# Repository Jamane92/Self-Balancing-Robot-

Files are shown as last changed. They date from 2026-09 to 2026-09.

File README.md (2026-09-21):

# Self-Balancing-Robot-

--FRANCAIS--

Ce projet à été réalisé individuellement en parallèle de mes études, reprend un projet que nous avions réalisé en ING1 à l'ECE Paris. Mais cette fois, au lieu de tout avoir déjà donné et pensé dans un kit, je me suis lancé le défi de tout faire moi même, de A à Z, de la 3D à la création du PCB, au codage du PID. Voici le résultat final : 

--ENGLISH

I carried out this project independently alongside my studies, revisiting a project we had originally completed during our first year of engineering school (ING1) at ECE Paris. This time, however, instead of using a kit where everything was pre-designed and provided, I challenged myself to build the entire thing from scratch—from 3D modeling and PCB design to programming the PID controller. Here is the final result : 

<p align="center">
  Self_Balancing
</p>

<p align="center">
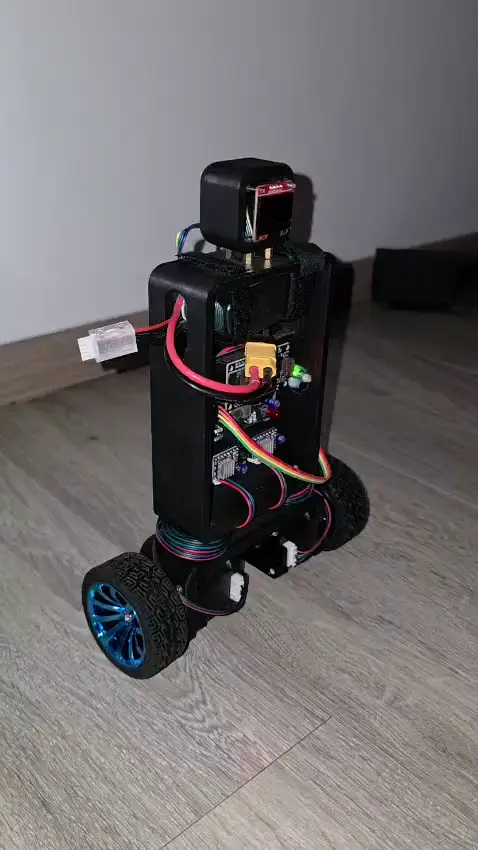
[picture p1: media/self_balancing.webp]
Démonstration du robot
  
</p>

--FRANCAIS--
Si souhaité, ce robort peut-être transformé en robot télécommandé, il suffit simplement de créer un serveur web sur l'EPS32 et d'y ajouter une modification de la consigne d'angle, ou de set un pitch/roll cible. 

Les difficultés rencontrés ont été sur le codage du PID, le fait que le buck-down choisi, le Mini360, ne donnait probablement pas suffisament de courant, bridant le couple et compliquant ainsi le codage du PID, j'ai également eu quelque problèmes avec le placement de mon MPU-6050, qui est un module bassse qualité, qui m'a beaucoup ralenti, en effet, pas malin d'acheter le coeur du projet à 3e sur Aliexpress au lieu de 15e chez le constructeur. Egalement celui-ci à été mal placé, ce que j'ai corrigé avec le point de col sur le coté pour le mettre à l'horizontal et non à la verticale ccomme il l'était. Aussi, j'ai "verser du cuivre" en GND sous l'antenne, ce qui n'est pas bon pour l'intégrité du signal radio et réduisait ainsi mes performances WIFI. C'est néanmoins un premier projet validé, qui me donne confiance pour plonger plus en détail dans le monde des PCB et de la conception hardware. 

--ENGLISH--
If desired, this robot can be converted into a remote-controlled unit; this simply requires setting up a web server on the ESP32 and adding a way to modify the angle setpoint or define a target pitch/roll.

I encountered difficulties with the PID coding, partly because the chosen step-down converter (the Mini360) likely didn't supply enough current—limiting torque and complicating PID tuning. I also faced issues with the placement of the MPU-6050; it was a low-quality module that really slowed me down—in hindsight, buying the project's core component for €3 on AliExpress instead of €15 from the manufacturer wasn't the smartest move. Furthermore, its initial positioning was incorrect; I fixed this by mounting it horizontally (using a side-mounted glue point) rather than vertically as it had been before. Finally, I had "poured copper" (a ground plane) beneath the antenna, which compromised radio signal integrity and reduced Wi-Fi performance. It is, however, a first project successfully completed, giving me the confidence to delve deeper into the world of PCBs and hardware design.

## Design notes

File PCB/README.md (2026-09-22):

--FRANCAIS-- 

Voici la section PCB du projet, j'y expose l'intégralité des documents nécessaires pour récupéerer le projet. Ce projet avait avant tout pour but de m'initier à la création de mon tout premier PCB, il n'utilise que des composants THT ou module complet que j'ai implémenté sur le PCB. Voici à quoi ressemble la 3D de mon PCB : 

--ENGLISH--

Here is the PCB section of the project; I have provided all the necessary documents to replicate it. The primary goal of this project was to learn how to design my very first PCB; it uses only through-hole (THT) components or complete modules that I mounted onto the board. Here is what the 3D view of my PCB looks like:

<p align="center">
  3D2
</p>

<p align="center">
  3D3
</p>

--FRANCAIS--

Et voici le routage, gardez à l'esprit que c'est mon tout premier PCB, avec que des composants THT, sans copper zone pour la puissance par exemple, sans plan de masse correct garantissant des EMI basses et une intégrité du signal, même si sur ce genre d'application, on est loin d'avoir ce genre de problème. L'important pour moi à ce moment là, c'était que ca marche, pour me donner la confiance d'aller sur des projets plus poussés.

--ENGLISH--

And here is the routing; keep in mind that this is my very first PCB, using only through-hole components, with no copper pour and no proper ground plane to ensure low EMI and signal integrity—though for this type of application, such issues are far from being a concern. The important thing for me at that point was for it to work, to give me the confidence to take on more advanced projects.

<p align="center">
robot
</p>

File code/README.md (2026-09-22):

--FRANCAIS-- 

Le code repose sur un concept d'automatisation utilisé partout dans le monde : le PID. Voici à quoi cela ressemble en théorie : 

<p align="center">
pid
</p>

Voici un site qui expliquera mieux que moi le concept de cet algorithme de contrôle : https://www.wattco.com/fr/2024/07/controleur-pid-explique/

--ENGLISH--

The code is based on an automation concept used worldwide: PID. Here up there is what it looks like in theory.
Here is a site that explains the concept of this control algorithm better than I can: https://www.wattco.com/fr/2024/07/controleur-pid-explique/

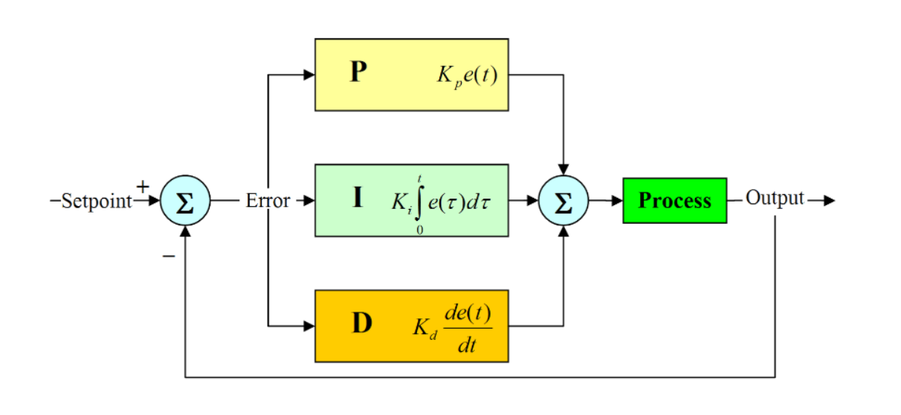
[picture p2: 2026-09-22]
media/pid.png

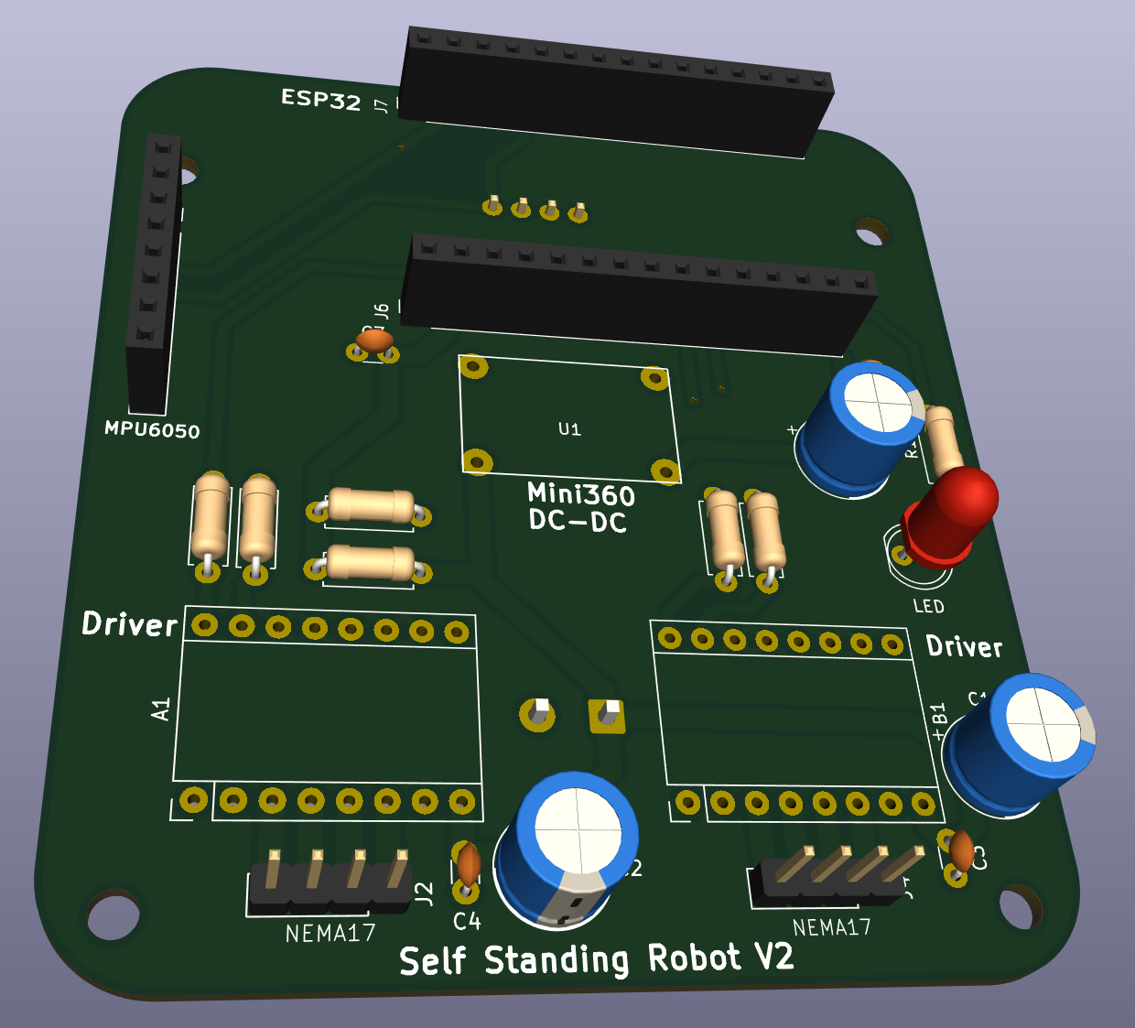
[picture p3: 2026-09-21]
media/3D2.png

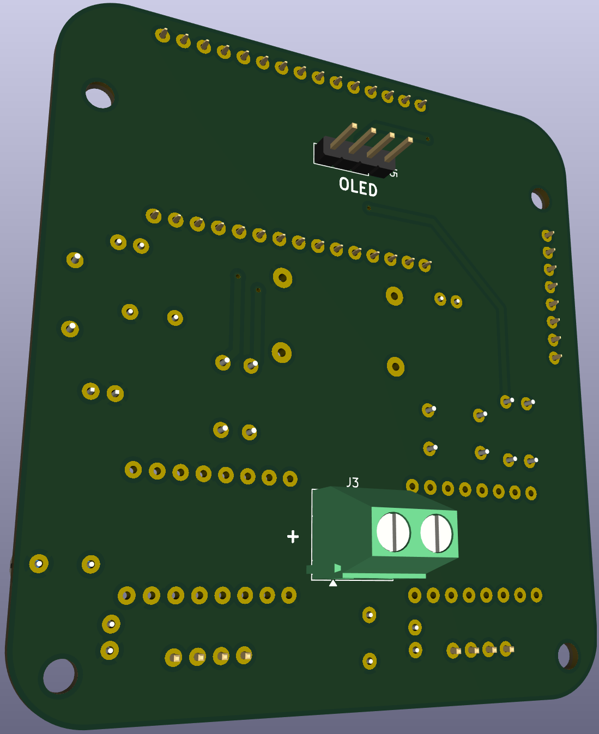
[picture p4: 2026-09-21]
media/3D3.png

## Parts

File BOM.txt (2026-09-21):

2x NEMA 17 DC motor 
2x DRV8825 motor driver
1x 3S1P Lipo battery 
1x ESP32 generic module 
1x Mini360 buck-down 
1x MPU-6050
1x SSD1306 OLED

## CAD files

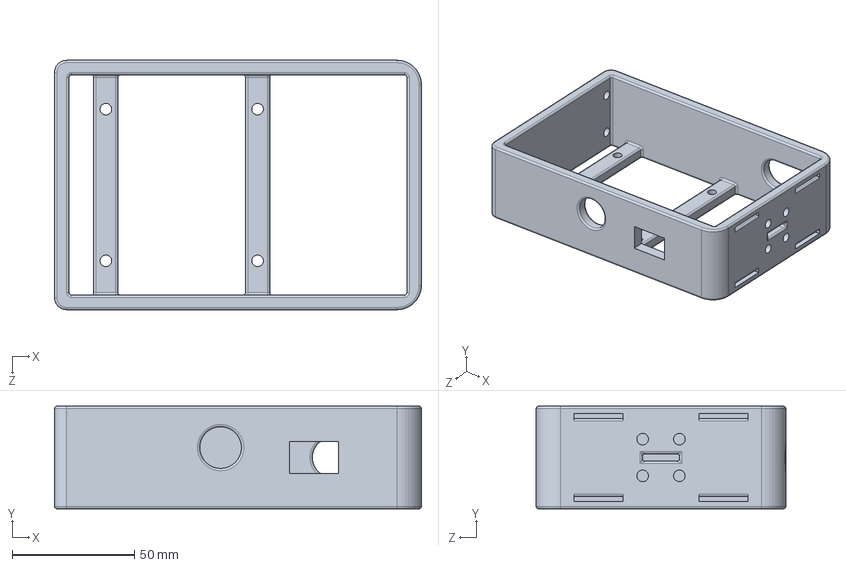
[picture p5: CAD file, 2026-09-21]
3D/body.SLDPRT
150.0 x 42.0 x 102.0 mm

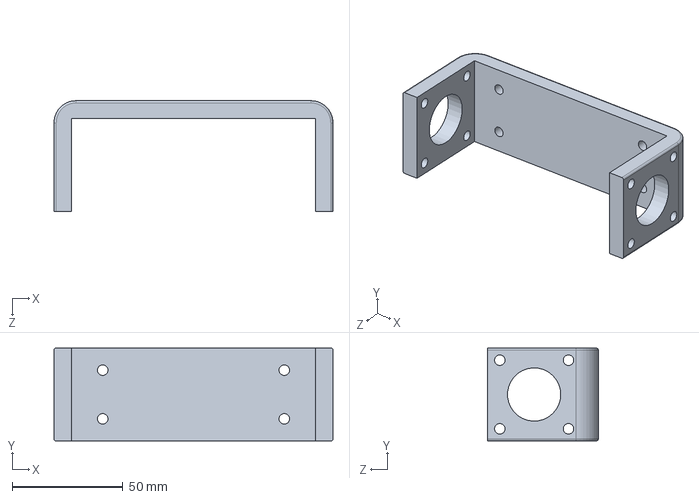
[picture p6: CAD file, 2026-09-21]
3D/legs.SLDPRT
126.0 x 42.0 x 50.0 mm

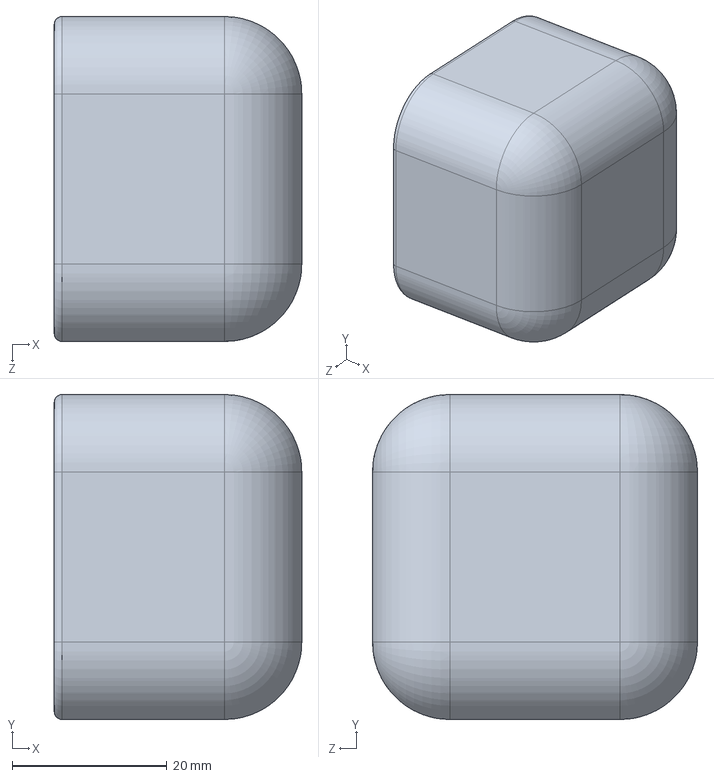
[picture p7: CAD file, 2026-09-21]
3D/head.SLDPRT
32.0 x 42.0 x 42.0 mm

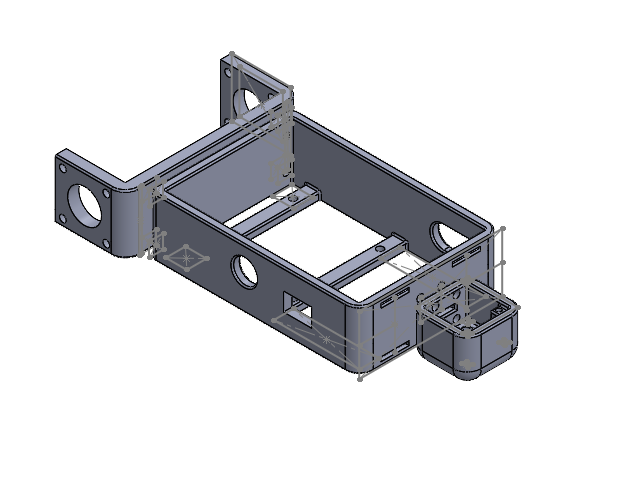
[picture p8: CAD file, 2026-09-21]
3D/assembly.SLDASM
Pièce1
Pièce2_V2
Pièce3_V2

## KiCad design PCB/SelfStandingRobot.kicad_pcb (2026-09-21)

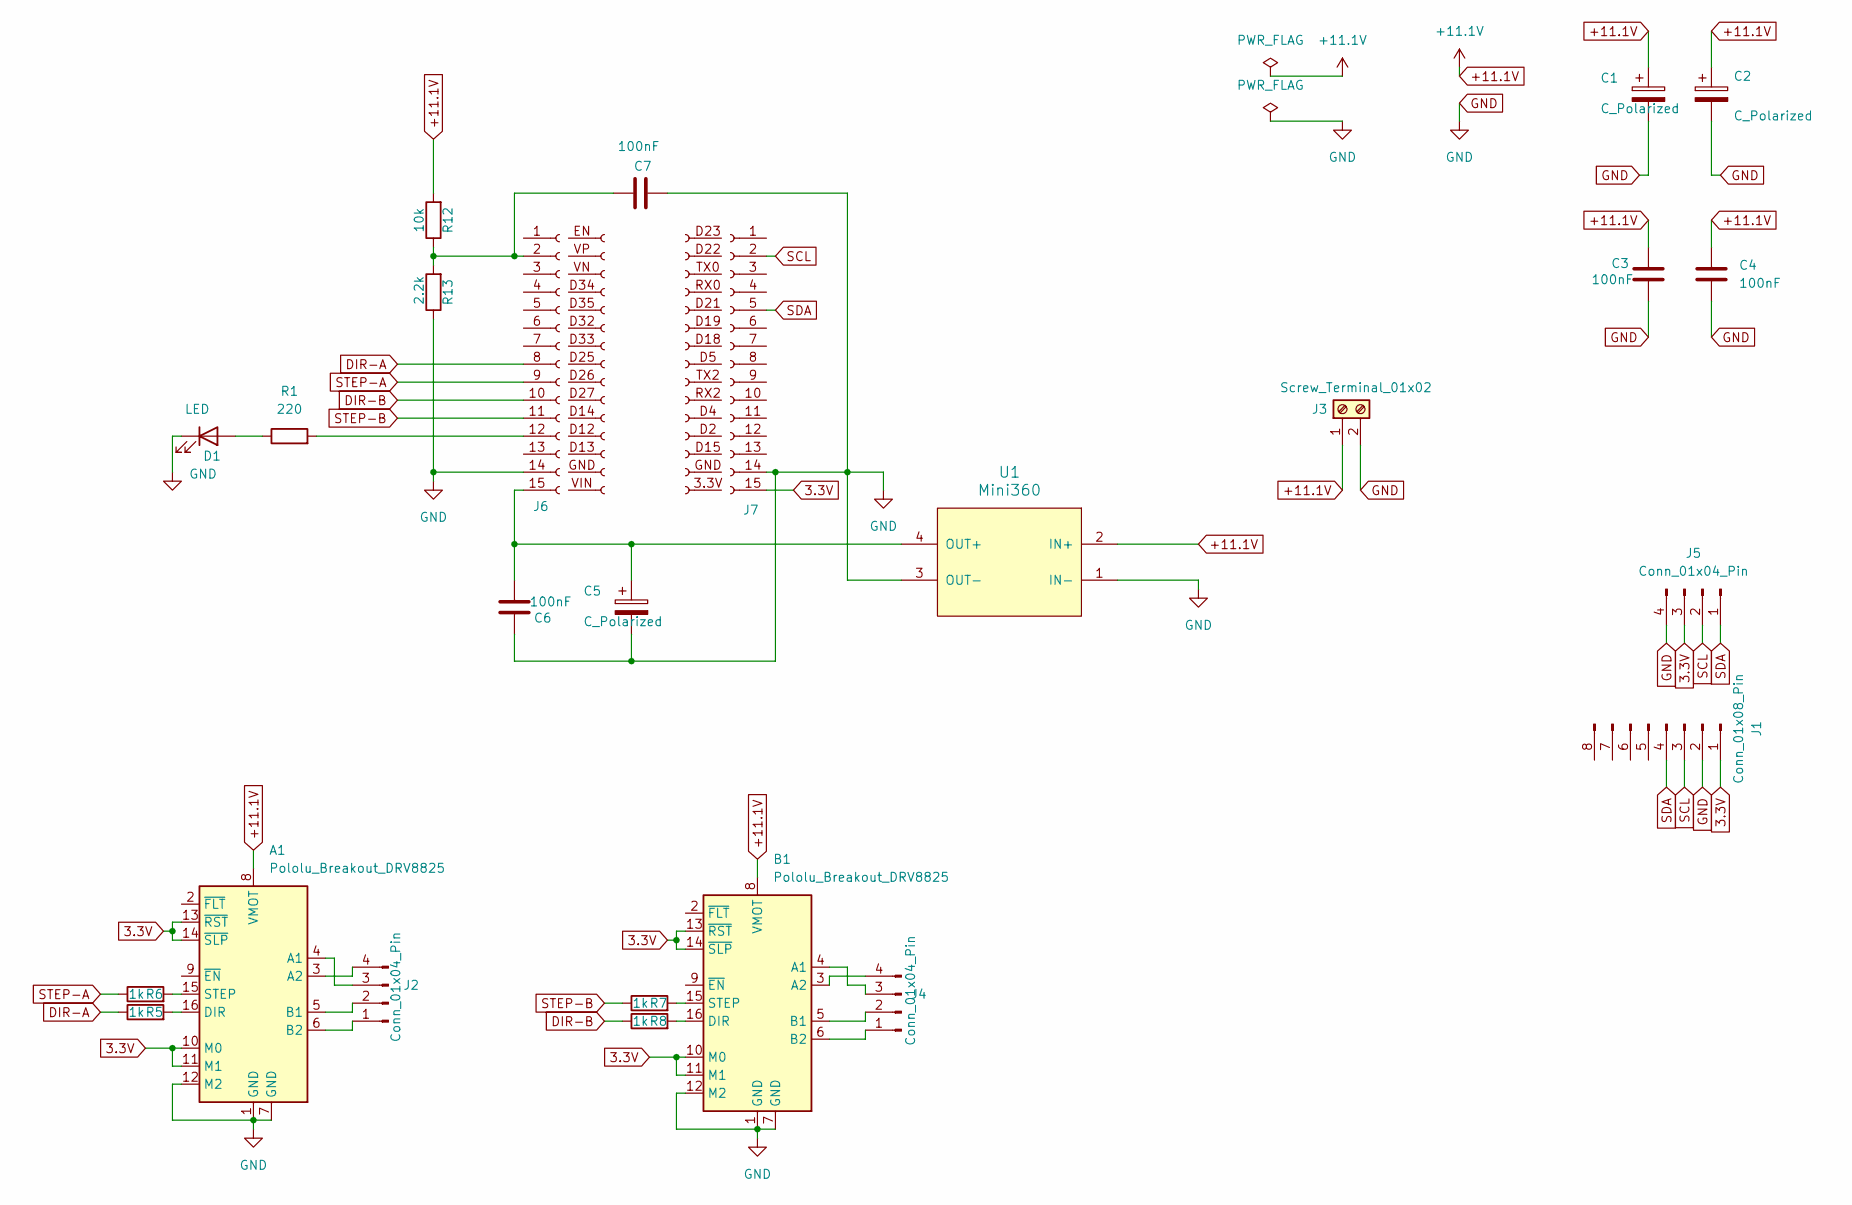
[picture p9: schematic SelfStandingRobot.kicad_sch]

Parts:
A1: Pololu_Breakout_DRV8825; Pololu_Breakout-16_15.2x20.3mm
B1: Pololu_Breakout_DRV8825; Pololu_Breakout-16_15.2x20.3mm
C1, C2, C5: C_Polarized; CP_Radial_D8.0mm_P5.00mm
C3, C4, C6, C7: 100nF; C_Disc_D3.0mm_W1.6mm_P2.50mm
D1: LED; LED_D5.0mm
J1: Conn_01x08_Pin; PinSocket_1x08_P2.54mm_Vertical
J2, J4, J5: Conn_01x04_Pin; PinHeader_1x04_P2.54mm_Vertical
J3: Screw_Terminal_01x02; TerminalBlock_Phoenix_MKDS-1,5-2-5.08_1x02_P5.08mm_Horizont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
J6, J7: Conn_01x15_Socket; PinSocket_1x15_P2.54mm_Vertical
J9, J10: Conn_01x15_Socket
R1: 220; R_Axial_DIN0207_L6.3mm_D2.5mm_P7.62mm_Horizontal
R5, R6, R7, R8: 1k; R_Axial_DIN0207_L6.3mm_D2.5mm_P7.62mm_Horizontal
R12: 10k; R_Axial_DIN0207_L6.3mm_D2.5mm_P7.62mm_Horizontal
R13: 2.2k; R_Axial_DIN0207_L6.3mm_D2.5mm_P7.62mm_Horizontal
U1: Mini360; Mini360_Step-Down

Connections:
3.3V: A1.10 (M0), A1.11 (M1), A1.13 (~RST), A1.14 (~SLP), B1.10 (M0), B1.11 (M1), B1.13 (~RST), B1.14 (~SLP), J1.1, J5.3, J7.15 (3.3V)
+11.1V: A1.8 (VMOT), B1.8 (VMOT), C1.1, C2.1, C3.1, C4.1, J3.1, R12.2, U1.2 (IN+)
DIR-A: J6.8 (D25), R5.1
DIR-B: J6.10 (D27), R8.1
GND: A1.1 (GND), A1.7 (GND), A1.12 (M2), B1.1 (GND), B1.7 (GND), B1.12 (M2), C1.2, C2.2, C3.2, C4.2, C5.2, C6.1, C7.1, D1.1 (K), J1.2, J3.2, J5.4, J6.14 (GND), J7.14 (GND), R13.1, U1.1 (IN-), U1.3 (OUT-)
unnamed: A1.4 (A1), J2.3
unnamed: A1.3 (A2), J2.4
unnamed: A1.5 (B1), J2.2
unnamed: A1.6 (B2), J2.1
unnamed: A1.16 (DIR), R5.2
unnamed: A1.15 (STEP), R6.2
unnamed: B1.4 (A1), J4.3
unnamed: B1.3 (A2), J4.4
unnamed: B1.5 (B1), J4.2
unnamed: B1.6 (B2), J4.1
unnamed: B1.16 (DIR), R8.2
unnamed: B1.15 (STEP), R7.2
unnamed: D1.2 (A), R1.1
unnamed: J6.12 (D12), R1.2
unnamed: C5.1, C6.2, J6.15 (VIN), U1.4 (OUT+)
unnamed: C7.2, J6.2 (VP), R12.1, R13.2
SCL: J1.3, J5.2, J7.2 (D22)
SDA: J1.4, J5.1, J7.5 (D21)
STEP-A: J6.9 (D26), R6.1
STEP-B: J6.11 (D14), R7.1

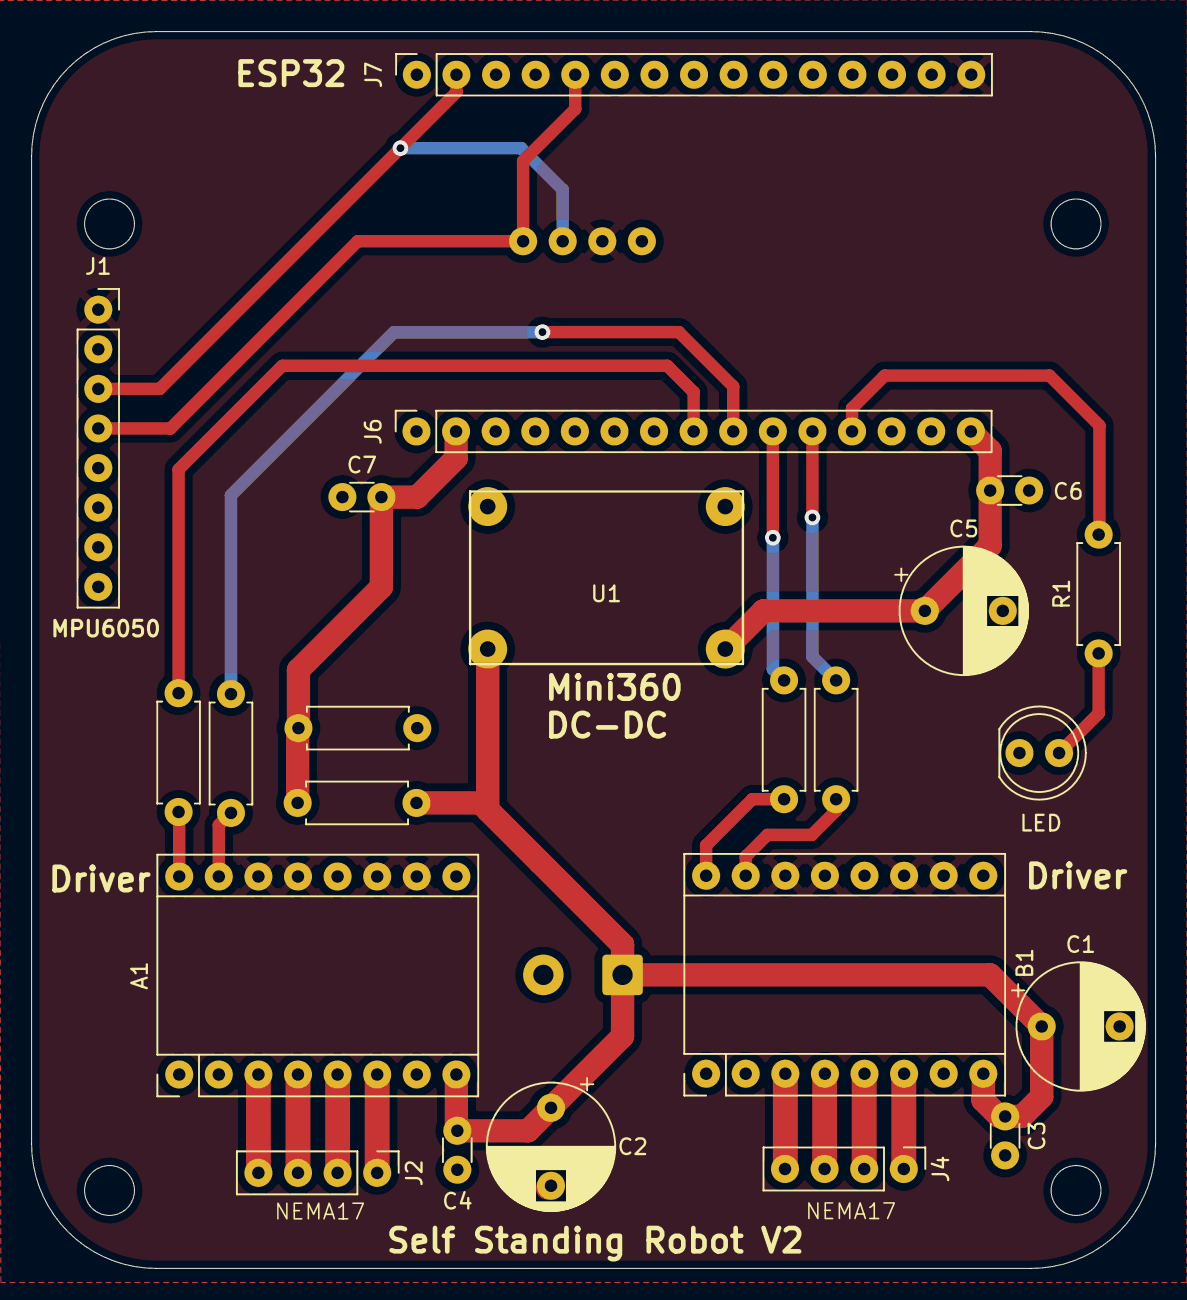
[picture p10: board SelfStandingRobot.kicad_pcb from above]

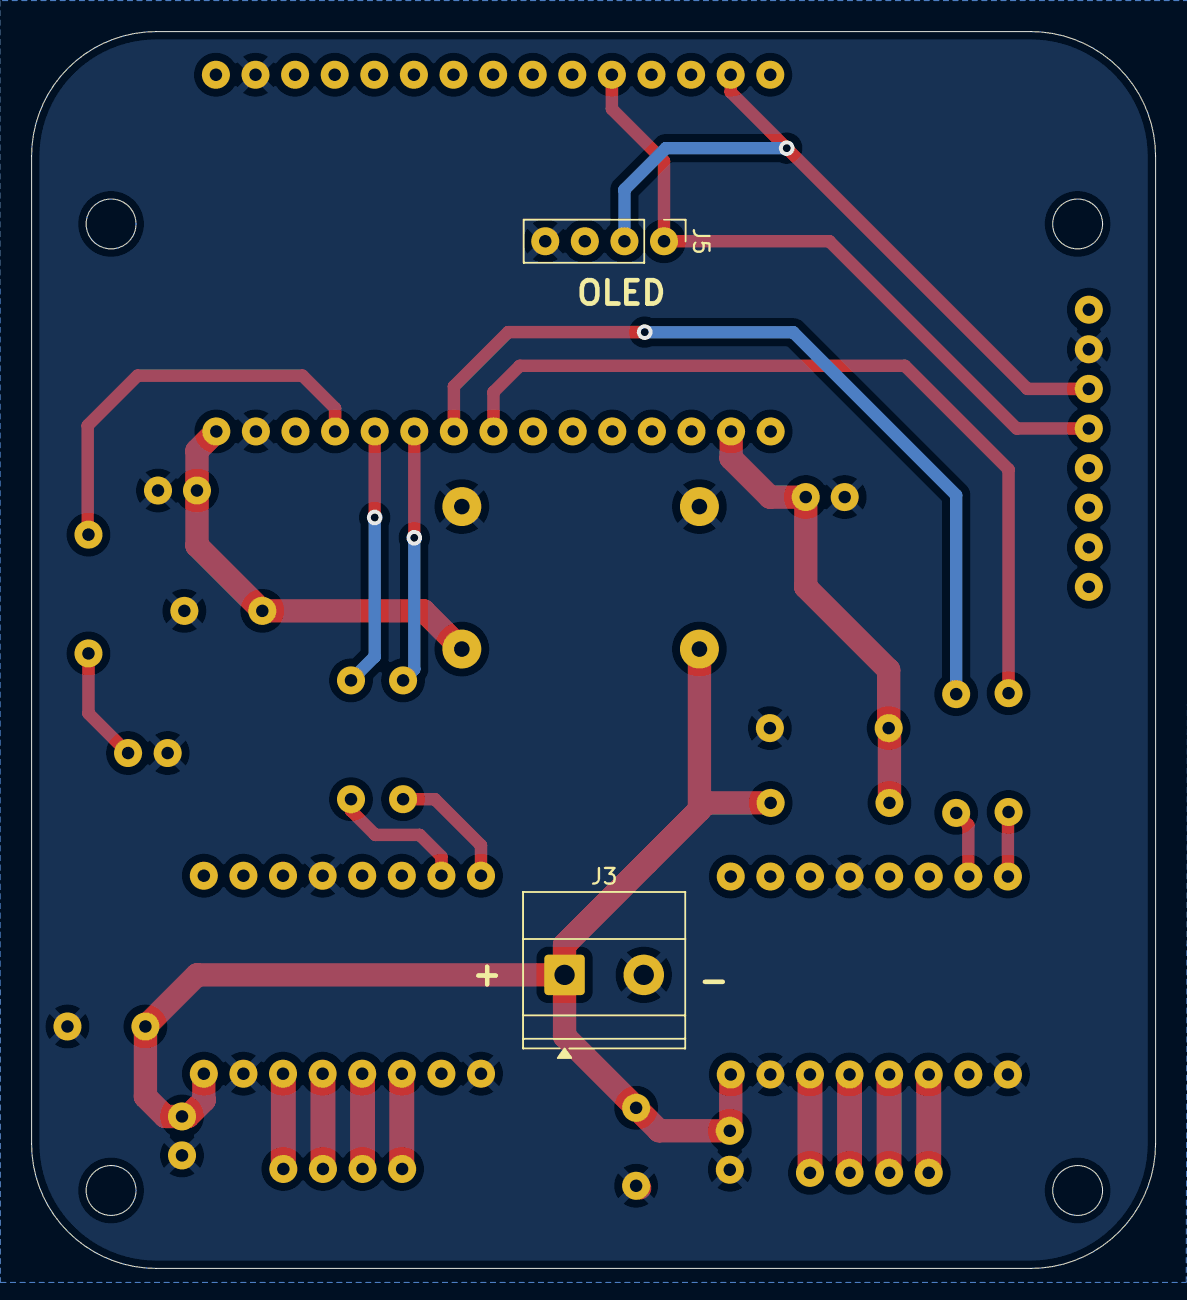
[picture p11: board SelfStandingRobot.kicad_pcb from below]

Board: 2 copper layers, 72.1 x 79.3 mm, 25 parts (2 on the bottom side), 25 nets.

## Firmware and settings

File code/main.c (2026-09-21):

//Board : ESP32

#include <Wire.h>
#include <Adafruit_GFX.h>
#include <Adafruit_SSD1306.h>
#include "FastAccelStepper.h"

// --- CONFIGURATION OLED ---
#define SCREEN_WIDTH 128
#define SCREEN_HEIGHT 64
Adafruit_SSD1306 display(SCREEN_WIDTH, SCREEN_HEIGHT, &Wire, -1);

// --- CONFIGURATION MOTEURS ---
#define DIR_PIN_A 25
#define STEP_PIN_A 26
#define DIR_PIN_B 27
#define STEP_PIN_B 14

FastAccelStepperEngine engine = FastAccelStepperEngine();
FastAccelStepper *stepperL = NULL;
FastAccelStepper *stepperR = NULL;

// --- CONFIGURATION BATTERIE & LED ---
const int ledPin = 12;
const int batteryPin = 36;
const float divisionFactor = 5.5454; 
const float calibrationFactor = 1.098;
float adcValue = 0;
float voltageOnPin = 0;
float batteryVoltage = 0;

// --- VARIABLES GLOBALES MPU6050 ---
int16_t gyro_x, gyro_y, gyro_z; 
int16_t acc_x, acc_y, acc_z;    
long acc_total_vector;
int16_t temperature;
long gyro_x_cal, gyro_y_cal, gyro_z_cal;
unsigned long loop_timer;       
float angle_pitch, angle_roll;
boolean set_gyro_angles;
float angle_roll_acc, angle_pitch_acc;
float angle_pitch_output, angle_roll_output;

// --- VARIABLES PID ---
float Kp = 325;  //525 //400
float Ki = 5;   //0.5 //3 //les deuxiemes parametres fonctionnent avec l'anti wind up d'activé
float Kd = 550; //50 //140
float integral, last_error, error, pid_output;

float setpoint = 0;

// --- NOUVEAUX PARAMÈTRES DE PERFORMANCE ---
float min_speed = 0; //100 // Vitesse minimale (Hz) pour vaincre l'inertie
float deadzone = 0.1;   //0,1
// Compteurs
int print_counter = 0;
int oled_counter = 0;
int led_counter = 0;
bool led_state = false;

void setup() {
  Wire.begin(21, 22);
  Wire.setClock(400000); 
  Serial.begin(115200);
  
  pinMode(2, OUTPUT);
  pinMode(ledPin, OUTPUT);
  
  analogSetAttenuation(ADC_11db);
  /*
  if(!display.begin(SSD1306_SWITCHCAPVCC, 0x3C)) { 
    Serial.println(F("SSD1306 introuvable"));
  }
  display.clearDisplay();
  display.setTextSize(1);
  display.setTextColor(WHITE);
  display.setCursor(0,0);
  display.println("MPU6050 + OLED");
  display.println("Calibrage...");
  display.display();
  */
  engine.init();
  stepperL = engine.stepperConnectToPin(STEP_PIN_A);
  if (stepperL) { 
    stepperL->setDirectionPin(DIR_PIN_A); 
    stepperL->setAcceleration(30000); 
  }
  stepperR = engine.stepperConnectToPin(STEP_PIN_B);
  if (stepperR) { 
    stepperR->setDirectionPin(DIR_PIN_B); 
    stepperR->setAcceleration(30000); 
  }
  delay(1000);
  setup_mpu_6050_registers();

  digitalWrite(2, HIGH); 
  for (int cal_int = 0; cal_int < 2000 ; cal_int ++){
    read_mpu_6050_data();
    gyro_x_cal += gyro_x;
    gyro_y_cal += gyro_y;
    gyro_z_cal += gyro_z;
    delay(3);
  }
  gyro_x_cal /= 2000;
  gyro_y_cal /= 2000;
  gyro_z_cal /= 2000;
  digitalWrite(2, LOW); 
  /*
  display.clearDisplay();
  display.setCursor(0,0);
  display.println("System Ready!");
  display.display();
  */
  delay(200);

  loop_timer = micros();
}

void loop(){
  // 1. Lecture et traitement IMU
  read_mpu_6050_data();
  gyro_x -= gyro_x_cal;
  gyro_y -= gyro_y_cal;
  gyro_z -= gyro_z_cal;
  
  angle_pitch += gyro_x * 0.0000611;
  angle_roll += gyro_y * 0.0000611;
  angle_pitch += angle_roll * sin(gyro_z * 0.000001066);
  angle_roll -= angle_pitch * sin(gyro_z * 0.000001066);
  
  acc_total_vector = sqrt((acc_x*acc_x)+(acc_y*acc_y)+(acc_z*acc_z));
  angle_pitch_acc = asin((float)acc_y/acc_total_vector)* 57.296;
  angle_roll_acc = asin((float)acc_x/acc_total_vector)* -57.296;
  
  if(set_gyro_angles){
    angle_pitch = angle_pitch * 0.9996 + angle_pitch_acc * 0.0004;
    angle_roll = angle_roll * 0.9996 + angle_roll_acc * 0.0004;
  } else {
    angle_pitch = angle_pitch_acc;
    angle_roll = angle_roll_acc;
    set_gyro_angles = true;
  }
  
  angle_pitch_output = angle_pitch_output * 0.9 + angle_pitch * 0.1;
  angle_roll_output = angle_roll_output * 0.9 + angle_roll * 0.1;

  // --- CALCUL PID ---
  error = angle_roll_output - setpoint; 

  // Anti-windup lors du changement de signe
  
if ((error > 0 && last_error < 0) || (error < 0 && last_error > 0)) {
    integral = 0;
}
  
// Accumulation conditionnelle
if (abs(error) > 0.3) {
    integral = constrain(integral + error, -5000, 5000); //test avec 3000, marchait avant avec -+1000 
} else {
    integral *= 0.9;  // Décroissance
}
  float D = Kd * (error - last_error);
  pid_output = (Kp * error) + (Ki * integral) + D;
  last_error = error;

  // --- CONTRÔLE MOTEURS AVEC OFFSET ---
  float speed_hz = 0;
  float current_abs_error = abs(error);

  if (current_abs_error > 30) {
    // Sécurité chute : On coupe tout
    stepperL->stopMove();
    stepperR->stopMove();
    integral = 0;
  } 
  else if (current_abs_error < deadzone) {
    // Zone de stabilité : On arrête les moteurs pour éviter sifflements et jitter
    stepperL->stopMove();
    stepperR->stopMove();
    speed_hz = 0;
  } 
  else {
    // On calcule la vitesse en ajoutant l'offset min_speed
    speed_hz = abs(pid_output) + min_speed;
    speed_hz = constrain(speed_hz, 0, 20000);

    if (pid_output < 0) {
      stepperL->setSpeedInHz((uint32_t)speed_hz); 
      stepperL->runForward();
      stepperR->setSpeedInHz((uint32_t)speed_hz); 
      stepperR->runBackward();
    } else {
      stepperL->setSpeedInHz((uint32_t)speed_hz); 
      stepperL->runBackward();
      stepperR->setSpeedInHz((uint32_t)speed_hz); 
      stepperR->runForward();
    }
  }

  // --- GESTION LED & AFFICHAGE ---
  led_counter++;
  if (led_counter >= 250) {
    led_state = !led_state;
    digitalWrite(ledPin, led_state); 
    led_counter = 0;
  }
  /*
  oled_counter++;
  if (oled_counter >= 25) {
    adcValue = analogRead(batteryPin);
    voltageOnPin = (adcValue * 3.3) / 4095.0;
    batteryVoltage = (voltageOnPin * divisionFactor) * calibrationFactor;

    display.clearDisplay();
    display.setCursor(0, 0);
    display.print("Roll: "); display.println(angle_roll_output, 1);
    display.setCursor(0, 15);
    display.print("Bat: "); display.print(batteryVoltage, 1); display.println("V");
    display.setCursor(0, 30);
    display.print("PID: "); display.print(pid_output, 0);
    display.setCursor(0, 45);
    display.print("Hz Total: "); display.println(speed_hz, 0);
    display.display();
    oled_counter = 0;
  }
  */
  while(micros() - loop_timer < 4000) yield();
  loop_timer = micros();
}

void read_mpu_6050_data(){
  Wire.beginTransmission(0x68);
  Wire.write(0x3B);
  Wire.endTransmission();
  Wire.requestFrom(0x68, 14);
  while(Wire.available() < 14);
  
  acc_x = (int16_t)(Wire.read()<<8|Wire.read());
  acc_y = (int16_t)(Wire.read()<<8|Wire.read());
  acc_z = (int16_t)(Wire.read()<<8|Wire.read());
  temperature = (int16_t)(Wire.read()<<8|Wire.read());
  gyro_x = (int16_t)(Wire.read()<<8|Wire.read());
  gyro_y = (int16_t)(Wire.read()<<8|Wire.read());
  gyro_z = (int16_t)(Wire.read()<<8|Wire.read());
}

void setup_mpu_6050_registers(){
  Wire.beginTransmission(0x68);
  Wire.write(0x6B);
  Wire.write(0x00);
  Wire.endTransmission();
  Wire.beginTransmission(0x68);
  Wire.write(0x1C);
  Wire.write(0x10);
  Wire.endTransmission();
  Wire.beginTransmission(0x68);
  Wire.write(0x1B);
  Wire.write(0x08);
  Wire.endTransmission();
}

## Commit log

2026-09-21 Add main.c for ESP32
2026-09-21 Add bill of materials for project components
2026-09-21 Update README with remote control instructions
    Added instructions for converting the robot into a remote-controlled version using a web server on the ESP32.
2026-09-21 Update PCB README with direct image links
    Replaced local image links with direct URLs for 3D PCB images.
2026-09-22 Add French section to README
    Add French introduction to README about PID automation concept.
2026-09-22 Update README with PID image
    Added an image representation of the PID concept in the README.
2026-09-22 Enhance README with details on first PCB experience
    Expanded explanation about the first PCB project, emphasizing the importance of functionality and confidence for future projects.
